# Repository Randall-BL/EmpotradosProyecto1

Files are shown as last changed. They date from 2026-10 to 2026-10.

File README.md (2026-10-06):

# Proyecto I — Robot Aspiradora Autónomo con Yocto

Curso **CE-1113 Sistemas Empotrados** — Instituto Tecnológico de Costa Rica
Robot aspiradora autónomo sobre **Raspberry Pi 4 Model B** con una imagen Linux mínima
construida con **Yocto Project (Poky, rama `scarthgap`)**.

El robot navega de forma autónoma evadiendo obstáculos con un radar ultrasónico (un
HC-SR04 sobre un servo de 180°) y un MPU-6050 que da su velocidad y el tiempo que falta
para chocar; reproduce MP3 por un amplificador PAM8403, y se controla remotamente desde
un servidor web embebido que muestra telemetría, el radar y el mapa de recorrido en
tiempo real. Todo el acceso al hardware pasa por una biblioteca dinámica propia
(`librobot.so`) compilada de forma cruzada para ARM.

> Estado del proyecto y desglose de tareas: [`TODO.md`](TODO.md) y los
> [issues del repositorio](https://github.com/Randall-BL/EmpotradosProyecto1/issues).

## Contenido

1. [Arquitectura del sistema](#1-arquitectura-del-sistema)
2. [Estructura del repositorio](#2-estructura-del-repositorio)
3. [Instalación](#3-instalación)
4. [Generación de la imagen Yocto](#4-generación-de-la-imagen-yocto)
5. [Compilación con la toolchain](#5-compilación-con-la-toolchain)
6. [Configuración y uso](#6-configuración-y-uso)
7. [API de la biblioteca dinámica](#7-api-de-la-biblioteca-dinámica)
8. [Paquetes agregados y su justificación](#8-paquetes-agregados-y-su-justificación)
9. [Evidencias de compilación cruzada](#9-evidencias-de-compilación-cruzada)
10. [Métricas de eficiencia de recursos](#10-métricas-de-eficiencia-de-recursos)
11. [Resultados](#11-resultados)
12. [Pruebas sin hardware](#12-pruebas-sin-hardware)
13. [Documentación](#13-documentación)
14. [Flujo de trabajo y licencia](#14-flujo-de-trabajo-y-licencia)

---

## 1. Arquitectura del sistema

### 1.1 Hardware

Dos fuentes independientes: un power bank USB alimenta la Raspberry Pi y todo lo que
trabaja a 5 V, y dos baterías alcalinas de 9 V en paralelo alimentan el puente H y los
motores. Las cuatro señales que cruzan del dominio lógico al de potencia —las entradas
del puente H— lo hacen por optoacopladores, y las dos tierras no se tocan en ningún
punto.

```mermaid
flowchart TB
    PB["Power bank USB · 5 V"]
    BAT["2 baterías de 9 V en paralelo"]

    subgraph LOG["Dominio lógico · GND_LOG"]
        PI["Raspberry Pi 4"]
        SERVO["Servo del radar"]
        HC["HC-SR04<br/>divisor 1k/2k en ECHO"]
        MPU["MPU-6050 (GY-521)"]
        IR["2 sensores IR al piso<br/>TCRT5000 / FC-51 a 3.3 V"]
        LED["4 LEDs indicadores"]
        AMP["Filtro RC + PAM8403"]
        SPK["Parlante 8 Ω"]
    end

    OPTO{{"4 × PC817 · aislamiento óptico"}}

    subgraph POT["Dominio de potencia · GND_POT"]
        L298["L298N"]
        MOT["2 motores DC"]
    end

    PB -- "USB-C" --> PI
    BAT -- "9 V" --> L298 --> MOT
    PI -- "5 V · GPIO 25" --> SERVO
    PI -- "GPIO 17 / 27" --- HC
    PI -- "I2C · GPIO 2 / 3" --- MPU
    PI -- "GPIO 4 / 8" --- IR
    PI -- "GPIO 16 · 20 · 21 · 26" --> LED
    PI -- "GPIO 18 · PWM" --> AMP --> SPK
    PI -. "GPIO 5 · 6 · 23 · 24" .-> OPTO
    OPTO -. "IN1–IN4" .-> L298
```

Los esquemas eléctricos dibujados están en
[`documentación/hardware-diagramas.pdf`](documentación/hardware-diagramas.pdf).

| Función | GPIO (BCM) | Nota |
|---|---|---|
| Motor derecho `IN1` / `IN2` (salida A) | 5 / 6 | Vía optoacoplador; `ENA` con jumper en el L298N |
| Motor izquierdo `IN3` / `IN4` (salida B) | 23 / 24 | Vía optoacoplador; `ENB` con jumper |
| Servo del radar | 25 | Señal directa; se alimenta de los 5 V de la Raspberry Pi |
| HC-SR04 `TRIG` / `ECHO` | 17 / 27 | `ECHO` con divisor 1 kΩ / 2 kΩ: el sensor entrega 5 V |
| MPU-6050 `SDA` / `SCL` | 2 / 3 | Módulo GY-521, alimentado de los 5 V de la Raspberry Pi |
| LED encendido / autónomo / manual / obstáculo | 16 / 20 / 21 / 26 | 5 mA cada uno |
| Sensores IR de desnivel izquierdo / derecho | 4 / 8 | Opcional. Módulos a 3.3 V, entradas con pull-down: sin módulo se lee "hay piso" |
| Audio PWM | 18 | Overlay `audremap`, filtro RC y PAM8403 |

El detalle —cálculos, listas de materiales y procedimientos de verificación— está en
[`docs/hardware-pinout.md`](docs/hardware-pinout.md),
[`docs/hardware-aislamiento.md`](docs/hardware-aislamiento.md),
[`docs/hardware-alimentacion.md`](docs/hardware-alimentacion.md),
[`docs/hardware-sensores.md`](docs/hardware-sensores.md) y
[`docs/hardware-chasis.md`](docs/hardware-chasis.md).

**Desviaciones acordadas con el profesor.** El diseño se aparta del enunciado en dos
puntos, ambos consultados con el profesor:

| Punto del enunciado | Lo que hace el robot | Motivo |
|---|---|---|
| Velocidad de los motores por PWM | Avanza, retrocede, gira y frena a velocidad fija, sin PWM | Los motores son lentos y de alto torque (60 rpm a 12 V) y trabajan a unos 9 V: con la tensión recortada por la PWM el robot no se mueve. Ver [`docs/hardware-aislamiento.md`](docs/hardware-aislamiento.md#velocidad-fija) |
| Al menos dos sensores de proximidad | Un HC-SR04 sobre un servo, que cubre el frente y los lados, y un MPU-6050 | El profesor lo consideró suficiente: lo que busca es que el robot tenga dos sensores. Ver [`docs/hardware-sensores.md`](docs/hardware-sensores.md) |

### 1.2 Software

```mermaid
flowchart TB
    WEB["Navegador del celular o la PC<br/>login.html · dashboard.html"]

    subgraph IMG["Imagen robot-image · Yocto scarthgap · systemd"]
        subgraph SRV["robot-server"]
            API["API REST y autenticación<br/>libmicrohttpd"]
            NAV["Hilo de navegación a 10 Hz<br/>evasión y mapa de 31 × 31"]
        end
        subgraph LIB["librobot.so.1"]
            MOTORES["lib_motors"]
            RADAR["lib_radar · lib_servo · lib_sensors<br/>hilo de barrido"]
            ODOM["lib_odom · lib_imu<br/>hilo de 50 Hz"]
            LEDS["lib_leds"]
            AUDIO["lib_audio<br/>hilo de reproducción"]
        end
        PIG["pigpiod<br/>GPIO · PWM y servo por DMA · I2C"]
        SND["mpg123 y ALSA"]
    end

    HW["L298N · servo · HC-SR04 · MPU-6050 · LEDs · PAM8403"]

    WEB -- "HTTP 8080 · JSON · cada 500 ms" --> API
    API --> NAV
    SRV -- "única vía de acceso al hardware" --> LIB
    MOTORES --> PIG
    RADAR --> PIG
    ODOM --> PIG
    LEDS --> PIG
    AUDIO --> SND
    PIG --> HW
    SND --> HW
```

| Componente | Qué hace |
|---|---|
| `robot-image` | Imagen sobre `core-image-minimal` con `systemd`, sin interfaz gráfica. La construye la capa propia `meta-robot`. |
| `librobot.so.1` | Biblioteca dinámica propia. Encapsula motores, radar, MPU-6050, odometría, LEDs y audio. Lanza tres hilos: odometría a 50 Hz, barrido del radar y reproducción de audio. |
| `robot-server` | Servidor HTTP en C sobre `libmicrohttpd`. Sirve el panel, expone la API y corre el hilo de navegación. Solo toca el hardware a través de `librobot`. |
| `pigpiod` | Demonio de GPIO. Genera PWM y pulsos de servo por DMA, mide el eco del HC-SR04 y da el bus I2C. Solo escucha en la interfaz local. |
| `robot-server.service` | Unidad `systemd` propia: arranque automático, `Requires=pigpiod.service` y `Restart=on-failure`. |

Cómo navega, cómo estima la velocidad y cómo construye el mapa:
[`docs/navegacion-radar.md`](docs/navegacion-radar.md).

---

## 2. Estructura del repositorio

```
.
├── lib/                    Biblioteca dinámica librobot.so (motores, radar, MPU-6050, LEDs, audio)
├── server/                 Servidor web embebido en C
│   ├── src/                  Código del servidor (API REST, autenticación, estado)
│   └── www/                  Interfaz web estática (login + dashboard)
├── audio/                  Recursos de audio
│   ├── notify_*.mp3          Sonidos de los 4 eventos del sistema
│   ├── canciones/            Playlist versionada, de dominio público
│   └── music/                Música propia (no se versiona, ver audio/README.md)
├── meta-robot/             Capa Yocto propia del proyecto
│   ├── conf/                 layer.conf, local.conf.sample y la máquina de QEMU
│   ├── recipes-image/        Receta de la imagen final (robot-image)
│   ├── recipes-multimedia/   Receta de librobot
│   ├── recipes-robot/        Receta del servidor web + unidad systemd
│   ├── recipes-support/      Receta de pigpio
│   ├── recipes-audio/        Configuración de ALSA
│   ├── recipes-connectivity/ Configuración de WiFi para arranque headless
│   ├── recipes-bsp/          Ajustes de config.txt y cmdline.txt
│   ├── recipes-kernel/       Fragmentos de configuración del kernel
│   └── wic/                  Tabla de particiones de la microSD
├── sim/                    Simulador de hardware: prueba librobot y el servidor sin la Raspberry
├── scripts/                Grabado de la microSD, medición de métricas, generación de la playlist
├── docs/                   Documentación técnica y evidencias
├── modelo-3d/              Carcasa impresa en 3D: modelo paramétrico (CadQuery), STL, STEP y vistas
├── documentación/          Documentos DI y AC, y diagramas de hardware (LaTeX y PDF)
├── CONTRIBUTING.md         Flujo de trabajo Git y convenciones de código
├── NOTICE.md               Atribución de software de terceros
└── TODO.md                 Desglose completo de requerimientos del enunciado
```

Los directorios de build de Yocto (`build/`, `tmp/`, `sstate-cache/`, `downloads/`) y los
artefactos de compilación (`*.o`, `*.so`, `CMakeFiles/`) están excluidos vía
[`.gitignore`](.gitignore): solo se versiona código fuente, recetas y documentación.

---

## 3. Instalación

### 3.1 Requisitos del host

Ubuntu 22.04 o 24.04, o Debian 12, de 64 bits.

| Recurso | Mínimo | Recomendado |
|---|---|---|
| Espacio en disco | 100 GB | 150 GB |
| RAM | 8 GB | 16 GB |
| Primer build | más de 5 horas | menos con más núcleos |

```bash
sudo apt update
sudo apt install -y gawk wget git diffstat unzip texinfo gcc build-essential \
    chrpath socat cpio python3 python3-pip python3-pexpect xz-utils \
    debianutils iputils-ping python3-git python3-jinja2 python3-subunit \
    zstd liblz4-tool file locales libacl1 bmap-tools
sudo locale-gen en_US.UTF-8
```

El build no puede hacerse sobre NTFS, exFAT ni un directorio de red. Con 8 GB de RAM o
menos hay que limitar el paralelismo: ver
[Hosts con poca memoria](docs/yocto-setup.md#hosts-con-poca-memoria).

### 3.2 Obtener el código

Poky, las capas y este repositorio, todos en la rama `scarthgap`:

```bash
mkdir -p ~/yocto && cd ~/yocto
git clone -b scarthgap https://git.yoctoproject.org/poky.git
cd poky
git clone -b scarthgap https://github.com/agherzan/meta-raspberrypi.git
git clone -b scarthgap https://github.com/openembedded/meta-openembedded.git
cd ..
git clone https://github.com/Randall-BL/EmpotradosProyecto1.git
```

---

## 4. Generación de la imagen Yocto

El procedimiento completo, con solución de problemas, está en
[`docs/yocto-setup.md`](docs/yocto-setup.md).

### 4.1 Agregar la capa `meta-robot/`

```bash
cd ~/yocto/poky
source oe-init-build-env            # crea build/ y deja la shell dentro

bitbake-layers add-layer ../meta-raspberrypi
bitbake-layers add-layer ../meta-openembedded/meta-oe
bitbake-layers add-layer ../meta-openembedded/meta-python
bitbake-layers add-layer ../meta-openembedded/meta-multimedia
bitbake-layers add-layer ../meta-openembedded/meta-networking
bitbake-layers add-layer ~/yocto/EmpotradosProyecto1/meta-robot

bitbake-layers show-layers          # deben aparecer las 8 capas
```

`meta-robot` se agrega **desde su ubicación dentro del repositorio clonado**. Las
recetas toman sus fuentes de `lib/`, `server/` y `audio/`, en la raíz del repositorio,
mediante `FILESEXTRAPATHS`: si se copia solo la carpeta de la capa, `do_fetch` falla.

### 4.2 Configurar el build

```bash
cat ~/yocto/EmpotradosProyecto1/meta-robot/conf/local.conf.sample >> conf/local.conf
```

Ese archivo lleva comentada la razón de cada variable. Lo esencial:

```
MACHINE ?= "raspberrypi4-64"
DISTRO_FEATURES:append = " systemd usrmerge wifi"
VIRTUAL-RUNTIME_init_manager = "systemd"
DISABLE_VC4GRAPHICS = "1"
ENABLE_I2C = "1"
RPI_KERNEL_DEVICETREE_OVERLAYS:append:rpi = " overlays/audremap.dtbo"
```

### 4.3 Credenciales de WiFi

El arranque es headless: el robot se conecta solo a la red. El archivo real está en
`.gitignore` y nunca se sube.

```bash
cd ~/yocto/EmpotradosProyecto1/meta-robot/recipes-connectivity/wifi-config/files
cp wpa_supplicant-wlan0.conf.sample wpa_supplicant-wlan0.conf
$EDITOR wpa_supplicant-wlan0.conf   # SSID y contraseña de la red
```

Si se omite, la receta usa la plantilla y `bitbake` avisa con un `WARNING`: la imagen se
construye igual, pero el robot no se conecta. Así un clon limpio produce la imagen sin
pasos manuales.

### 4.4 Construir

```bash
cd ~/yocto/poky/build
bitbake robot-image
```

Resultado:
`tmp/deploy/images/raspberrypi4-64/robot-image-raspberrypi4-64.rootfs.wic.bz2`.

### 4.5 Las recetas propias

| Receta | Qué integra |
|---|---|
| [`librobot_1.0.bb`](meta-robot/recipes-multimedia/librobot/librobot_1.0.bb) | La biblioteca dinámica de control |
| [`robot-server_1.0.bb`](meta-robot/recipes-robot/robot-server/robot-server_1.0.bb) | El servidor web, la interfaz, los audios y la unidad `systemd` |
| [`pigpio_1.0.bb`](meta-robot/recipes-support/pigpio/pigpio_1.0.bb) | `pigpio` desde su repositorio, con `SRCREV` fijo, y `pigpiod.service` |
| [`alsa-config_1.0.bb`](meta-robot/recipes-audio/alsa-config/alsa-config_1.0.bb) | `asound.conf` que dirige el audio a la salida PWM |
| [`wifi-config.bb`](meta-robot/recipes-connectivity/wifi-config/wifi-config.bb) | Credenciales de WiFi y configuración de red |
| [`robot-image.bb`](meta-robot/recipes-image/images/robot-image.bb) | La imagen final |

Cómo cumple `librobot_1.0.bb` lo que pide el enunciado:

```bitbake
# Copia las fuentes: viven en lib/, en la raíz del repositorio
FILESEXTRAPATHS:prepend := "${THISDIR}/../../../lib:${THISDIR}/../../..:"
SRC_URI = "file://lib_motors.c;subdir=lib file://lib_motors.h;subdir=lib ... \
           file://CMakeLists.txt;subdir=lib file://LICENSE;subdir=lib"
S = "${WORKDIR}/lib"

# Declara las dependencias de compilación y de ejecución
DEPENDS = "mpg123 alsa-lib"
DEPENDS:append:rpi = " pigpio"
RDEPENDS:${PN}:rpi = "pigpio-bin-pigpiod"

# Invoca CMake con la toolchain de Yocto
inherit cmake

# Instala los artefactos: el .so en la imagen, los headers en el paquete -dev
FILES:${PN}     = "${libdir}/librobot.so.1*"
FILES:${PN}-dev = "${libdir}/librobot.so ${includedir}/robot/*.h"
```

`robot-server_1.0.bb` agrega la unidad `systemd`, habilitada desde la receta y no a mano
en el target:

```bitbake
DEPENDS = "libmicrohttpd librobot"
inherit cmake systemd
SYSTEMD_SERVICE:${PN} = "robot-server.service"
SYSTEMD_AUTO_ENABLE = "enable"
```

El contenido de la capa está descrito en [`meta-robot/README.md`](meta-robot/README.md).

### 4.6 Grabar la microSD

```bash
./scripts/grabar-sd.sh              # busca la tarjeta, pide confirmación y verifica
```

O a mano:

```bash
cd tmp/deploy/images/raspberrypi4-64/
bzip2 -dk robot-image-raspberrypi4-64.rootfs.wic.bz2
lsblk                               # identificar el dispositivo antes de escribir
sudo bmaptool copy --nobmap robot-image-raspberrypi4-64.rootfs.wic /dev/sdX
```

La tarjeta queda con tres particiones, ninguna de más de 200 MB: `boot` (130 MiB),
`root` (180 MiB) y `canciones` (180 MiB).

---

## 5. Compilación con la toolchain

Nada se compila en la Raspberry Pi: la imagen no trae compilador. Además del build de
BitBake, el Toolchain-SDK permite compilar y probar un cambio sin reconstruir la imagen.
Detalle en [`docs/sdk.md`](docs/sdk.md).

### 5.1 Generar e instalar el SDK

```bash
cd ~/yocto/poky && source oe-init-build-env
bitbake -c populate_sdk robot-image

./tmp/deploy/sdk/poky-glibc-x86_64-robot-image-cortexa72-raspberrypi4-64-toolchain-*.sh \
    -y -d ~/robot-sdk
```

### 5.2 Compilar la biblioteca y el servidor

```bash
source ~/robot-sdk/environment-setup-cortexa72-poky-linux

cd ~/yocto/EmpotradosProyecto1/lib
mkdir -p build && cd build
cmake -DCMAKE_TOOLCHAIN_FILE=$OECORE_NATIVE_SYSROOT/usr/share/cmake/OEToolchainConfig.cmake ..
make -j$(nproc)

cd ~/yocto/EmpotradosProyecto1/server/src
mkdir -p build && cd build
cmake -DCMAKE_TOOLCHAIN_FILE=$OECORE_NATIVE_SYSROOT/usr/share/cmake/OEToolchainConfig.cmake ..
make -j$(nproc)
```

Cada terminal nueva necesita su `source`. Si `cmake` toma el compilador del host, casi
siempre faltó ese paso.

### 5.3 Verificar y probar en el target

```bash
file librobot.so.1.0.0
# ELF 64-bit LSB shared object, ARM aarch64, version 1 (SYSV), dynamically linked

scp librobot.so.1.0.0 root@<ip-del-robot>:/usr/lib/
scp robot-server      root@<ip-del-robot>:/usr/bin/
ssh root@<ip-del-robot> 'ldconfig && systemctl restart robot-server'
```

Sirve para iterar. Lo que se entrega es la imagen que produce `bitbake robot-image`.

---

## 6. Configuración y uso

### 6.1 Primer arranque

1. Insertar la microSD y encender el interruptor principal.
2. El robot arranca solo, sin pantalla ni teclado. Cuando el servidor está listo se
   enciende el **LED verde** y suena el aviso de inicio. Hay que dejarlo quieto en el
   piso durante ese primer segundo: el MPU-6050 se calibra al arrancar.
3. Buscar la IP que tomó el robot en la lista de clientes del router o del punto de
   acceso. También sirve la consola serie (115200 8N1) y
   `ip a`.

### 6.2 Panel de control

Abrir `http://<ip-del-robot>:8080` desde el celular o la PC, en la misma red.

| | |
|---|---|
| Usuario | `user1` |
| Contraseña | `password1` |

La sesión caduca a los 10 minutos de inactividad. El panel tiene tres pestañas:

| Pestaña | Qué ofrece |
|---|---|
| **Control** | Botones de modo autónomo y manual, ciclo de limpieza (meta por tiempo o por área, progreso y aviso de fin), controles direccionales, velocidad, estado de los cuatro LEDs y de los sensores de desnivel. Los motores van a velocidad fija, así que el control de velocidad no cambia la velocidad real |
| **Mapa** | La grilla de recorrido, el radar con las distancias a la izquierda, al frente y a la derecha, la velocidad que da el MPU-6050 y el tiempo antes de chocar, en tiempo real |
| **Audio** | Lista de canciones, reproducir, pausar, detener y volumen, y la playlist persistente: agregar con `+`, reordenar con ▲ ▼, quitar con ✕ y reproducirla completa |

### 6.3 Modos de operación

- **Autónomo.** El robot avanza y, al detectar un obstáculo, se detiene, retrocede, mira
  alrededor con el radar y gira hacia el lado más libre. Los controles direccionales
  quedan bloqueados.
- **Manual.** Los controles direccionales mandan los motores mientras se mantienen
  presionados. En la PC también funcionan las flechas y `W` `A` `S` `D`; la barra
  espaciadora detiene. Si aparece un obstáculo al frente, el robot frena solo.

**Desnivel (opcional).** Dos sensores infrarrojos en las esquinas delanteras miran al
piso. Si uno deja de ver piso —el borde de una grada—, el robot frena en cualquier modo.
En autónomo además retrocede y gira hacia el lado contrario (con los dos sensores, media
vuelta); en manual se niega a avanzar (`409`) hasta que se retroceda o se gire.

**Ciclo de limpieza (opcional).** Desde la pestaña Control se fija una meta: minutos en
modo autónomo o metros cuadrados recorridos (celdas nuevas del mapa × 0.09 m²). Al
cumplirla el robot se detiene, suena el aviso de fin de ciclo y el panel muestra
"Ciclo completado". Sigue quieto hasta que se pulse **Nuevo ciclo** o se vuelva a pedir
el modo autónomo.

### 6.4 Indicadores y sonidos

| LED | Color | Significado |
|---|---|---|
| Encendido | Verde | Sistema energizado y servidor activo |
| Autónomo | Azul | Modo autónomo en curso |
| Manual | Amarillo | Modo manual en curso |
| Obstáculo | Rojo | Obstáculo o desnivel detectado |

Hay un sonido para cada evento: inicio del sistema, inicio del modo autónomo, obstáculo
o desnivel detectado, cambio a modo manual y fin del ciclo de limpieza. El aviso pausa la
música y la reanuda al terminar.

### 6.5 Audio

Las canciones están en `/opt/robot/audio/canciones/`, en su propia partición. Una pista
elegida suelta se repite hasta que se detiene o se elige otra.

**Playlist persistente (opcional).** La lista ordenada que se arma en la pestaña Audio se
guarda en `/opt/robot/audio/canciones/playlist.txt`, un nombre de archivo por línea, en
la partición de la música: sobrevive a los reinicios. Se escribe en un temporal y se
renombra, así un corte de energía no la deja a medias. "Reproducir playlist" recorre la
lista en orden y vuelve a empezar al terminar. Sin archivo, la playlist son todas las
canciones.

Para agregar música:

- **Antes de construir:** copiar los MP3 a `audio/music/` (no se versiona).
- **Con el robot en marcha:** `scp cancion.mp3 root@<ip>:/opt/robot/audio/canciones/` y
  reiniciar el servicio.

### 6.6 Mapa de recorrido

Grilla de 31 × 31 celdas de 30 cm, con el robot empezando en el centro.

| Estado | Cuándo |
|---|---|
| Visitada | El centro del robot estuvo en la celda |
| Obstáculo | Un eco del radar cayó en la celda |
| Desconocida | Todo lo demás |

### 6.7 API HTTP

Todos los endpoints salvo el login exigen la cookie de sesión.

| Método y ruta | Cuerpo | Qué hace |
|---|---|---|
| `POST /api/login` | `{"username","password"}` | Inicia sesión |
| `POST /api/logout` | — | Cierra la sesión |
| `GET /api/status` | — | Modo, sensores, radar, movimiento, LEDs, audio y mapa |
| `POST /api/mode` | `{"mode":"autonomous"}` o `"manual"` | Cambia de modo |
| `POST /api/move` | `{"direction":"forward","speed":70}` | Mueve el robot, solo en modo manual. `direction`: `forward`, `backward`, `left`, `right`, `stop` |
| `GET /api/audio/list` | — | Lista de pistas |
| `POST /api/audio/control` | `{"action":"play","track_id":1}` | `play`, `pause`, `resume`, `stop`, `play_playlist` con `"index"`, o `seek` con `"position"` en segundos (la barra de progreso del panel) |
| `POST /api/audio/volume` | `{"volume":55}` | Volumen de 0 a 100 |
| `GET /api/audio/playlist` | — | Ids de la playlist en orden y la posición que suena |
| `POST /api/audio/playlist` | `{"ids":[3,1,9]}` | Reemplaza la playlist y la guarda en la SD |
| `POST /api/ciclo` | `{"tipo":"tiempo","minutos":5}`, `{"tipo":"area","m2":4}`, `{"tipo":"off"}` o `{"accion":"nuevo"}` | Configura la meta del ciclo de limpieza o empieza uno nuevo |

`GET /api/status` incluye además `ciclo` (tipo, meta, avance, `completo`) y `caida`
(sensores izquierdo y derecho, y eventos).

### 6.8 Cambiar la configuración

| Qué | Dónde | Después |
|---|---|---|
| Red WiFi | `wpa_supplicant-wlan0.conf` de la receta `wifi-config` | `bitbake -c cleansstate wifi-config && bitbake robot-image` |
| Usuario y contraseña | Tabla de usuarios en `server/src/auth.c`; el resumen sale de `echo -n 'clave' \| sha256sum` | Reconstruir la imagen |
| Umbrales de obstáculo y velocidades | Constantes de `server/src/main.c` y `lib/*.h` | Ver [`docs/odometria.md`](docs/odometria.md) |
| Pines | `#define` de la biblioteca | Ver [`docs/hardware-pinout.md`](docs/hardware-pinout.md) |

### 6.9 Diagnóstico

El robot no tiene pantalla: todo va al journal.

```bash
systemctl status robot-server
journalctl -u robot-server -f       # en vivo
journalctl -u pigpiod -b
```

Arranque automático y recuperación ante fallos:
[`docs/arranque-automatico.md`](docs/arranque-automatico.md).

---

## 7. API de la biblioteca dinámica

`librobot.so.1` es la única vía de acceso al hardware. Se enlaza con `-lrobot` y sus
headers están bajo `robot/`. Toda función que devuelve `int` usa `0` para éxito y `-1`
para error; las lecturas de distancia devuelven `-1.0` si no hubo eco.

La referencia completa, con tipos y ejemplos, está en
[`docs/api-librobot.md`](docs/api-librobot.md).

| Módulo | Funciones |
|---|---|
| **Fachada** `lib_robot.h` | `robot_init()` · `robot_shutdown()` · `robot_activo()` · `robot_distancia_frontal()` · `robot_distancia_izquierda()` · `robot_distancia_derecha()` |
| **Motores** `lib_motors.h` | `motores_set(izq, der)` · `motores_get()` · `motores_detener()` · `motores_avanzar(v)` · `motores_retroceder(v)` · `motores_girar_izquierda(v)` · `motores_girar_derecha(v)` · `motores_curva(v, giro)` |
| **Sensor** `lib_sensors.h` | `sensor_init()` · `sensor_leer_distancia()` |
| **Servo** `lib_servo.h` | `servo_init()` · `servo_mover(grados)` · `servo_angulo()` · `servo_liberar()` |
| **Radar** `lib_radar.h` | `radar_iniciar()` · `radar_detener()` · `radar_pausar()` · `radar_angulo_actual()` · `radar_lecturas()` · `radar_distancia(angulo)` · `radar_seq()` · `radar_barrido_completo()` · `radar_esperar_barrido()` · `radar_tiempo_choque()` · `radar_estado_choque()` · `radar_rayo()` |
| **Desnivel** `lib_caida.h` | `caida_init()` · `caida_leer()` |
| **MPU-6050** `lib_imu.h` | `imu_init()` · `imu_calibrar()` · `imu_leer()` · `imu_disponible()` · `imu_cerrar()` |
| **LEDs** `lib_leds.h` | `lib_leds_init()` · `lib_leds_set(led, estado)` · `lib_leds_get(led)` · `lib_leds_sync_from_state()` · `lib_leds_destroy()` |
| **Odometría** `lib_odom.h` | `odom_init()` · `odom_arrancar()` · `odom_parar()` · `odom_reset()` · `odom_update()` · `odom_get(x, y, rumbo)` · `odom_velocidad_cm_s()` · `odom_avance_cm()` · `odom_distancia_recorrida()` · `odom_get_velocidades()` · `odom_usa_imu()` |
| **Audio** `lib_audio.h` | `lib_audio_init(dir)` · `lib_audio_destroy()` · `lib_audio_scan()` · `lib_audio_get_tracks()` · `lib_audio_play(id)` · `lib_audio_pause()` · `lib_audio_resume()` · `lib_audio_stop()` · `lib_audio_seek(segundos)` · `lib_audio_set_volume(v)` · `lib_audio_get_volume()` · `lib_audio_get_status()` · `lib_audio_get_current_id()` · `lib_audio_get_position()` · `lib_audio_notify(evento)` · `lib_audio_playlist_get()` · `lib_audio_playlist_set()` · `lib_audio_play_playlist(pos)` · `lib_audio_playlist_pos()` |

Ejemplo mínimo:

```c
#include <robot/lib_robot.h>
#include <robot/lib_motors.h>
#include <robot/lib_radar.h>

int main(void) {
    if (robot_init() != 0) return 1;            /* con el robot quieto: calibra el MPU */
    while (trabajando) {
        double f   = robot_distancia_frontal();
        double ttc = radar_tiempo_choque();
        if ((f > 0 && f < 20.0) || (ttc >= 0 && ttc < 1.2))
            motores_detener();                  /* evadir */
        else
            motores_avanzar(200);
        usleep(100000);                         /* la odometría y el radar corren solos */
    }
    robot_shutdown();
    return 0;
}
```

---

## 8. Paquetes agregados y su justificación

La imagen parte de `core-image-minimal`, el punto de partida más pequeño de Poky. Todo lo
que se agrega está aquí; la discusión completa, con lo que se dejó fuera a propósito,
está en [`docs/paquetes.md`](docs/paquetes.md).

| Paquete | Justificación |
|---|---|
| `librobot` | Biblioteca dinámica de control. Obligatoria: única vía de acceso al hardware. |
| `robot-server` | Servidor web de control remoto. Obligatorio. |
| `wifi-config` | Credenciales y configuración de `wlan0`. Sin esto el arranque headless no llega a la red. |
| `alsa-config` | `asound.conf` que fuerza la salida PWM analógica. Sin esto ALSA elige HDMI. |
| `libmicrohttpd` | Servidor HTTP enlazable en C: un proceso menos que nginx o lighttpd, y pocos cientos de KB. |
| `mpg123` | Decodificador MP3, el más liviano con API en C. GStreamer traería decenas de MB. |
| `alsa-utils` | `amixer` para el control de volumen y `aplay` para diagnosticar la salida de audio. |
| `alsa-lib` | Runtime de ALSA; entra como dependencia de `librobot` y `mpg123`. |
| `pigpio`, `libpigpio`, `libpigpio_if2` | Acceso a GPIO con pulsos de servo de temporización estable, medición del eco en microsegundos e I2C. |
| `pigpio-bin-pigpiod` | El demonio al que se conecta `librobot`. |
| `wpa-supplicant` | Autenticación WPA2: la única forma de que un sistema headless se una solo a la red. |
| `wireless-regdb-static` | Base regulatoria; sin ella el kernel restringe canales y potencia. |
| `linux-firmware-rpidistro-bcm43455` | Firmware del chip WiFi de la Raspberry Pi 4. |
| `iw`, `rfkill` | Diagnóstico del enlace inalámbrico sin pantalla. Pocos KB. |
| `kernel-module-brcmfmac`, `-brcmfmac-wcc`, `-brcmutil` | Driver del chip WiFi Broadcom. |
| `kernel-module-snd`, `-snd-pcm`, `-snd-bcm2835` | Subsistema de sonido y driver de la salida de audio. |
| `kernel-module-i2c-bcm2835`, `-i2c-dev` | Bus I2C del MPU-6050. |
| `dhcpcd` | Solo en la imagen de QEMU, donde pide la IP. En la Raspberry la red la lleva `systemd-networkd`. |

Los módulos de kernel se listan uno por uno porque el paquete `kernel-modules` completo
sumaría decenas de MB de drivers que el robot no usa.

**Acceso remoto:** `ssh-server-openssh`, `openssh-sftp-server` y `debug-tweaks` dan
acceso al sistema sin pantalla y permiten recoger las métricas y diagnosticar el robot.

**Fuera a propósito:** entorno gráfico, driver VC4 y Mesa, GStreamer, Python 3,
`i2c-tools`, nginx y lighttpd, Bluetooth y el paquete `kernel-modules` completo.

---

## 9. Evidencias de compilación cruzada

Todas están en [`docs/evidencias/`](docs/evidencias/), generadas en un build real de
`bitbake robot-image`: host x86_64, target `raspberrypi4-64` (Cortex-A72).

### 9.1 Fragmento del log de Yocto

De `tmp/work/cortexa72-poky-linux/librobot/1.0/temp/log.do_compile`, con las rutas
abreviadas. El compilador es el cruzado, `aarch64-poky-linux-gcc`, invocado desde el
`recipe-sysroot-native`; el `gcc` del host no interviene.

```
[1/6] …/recipe-sysroot-native/usr/bin/aarch64-poky-linux/aarch64-poky-linux-gcc
      --sysroot=…/librobot/1.0/recipe-sysroot -Drobot_EXPORTS …
[5/6] : && …/aarch64-poky-linux-gcc --sysroot=…/recipe-sysroot -fPIC
      -mcpu=cortex-a72+crc -mbranch-protection=standard -fstack-protector-strong
      -O2 -D_FORTIFY_SOURCE=2 …
```

Los fragmentos sin abreviar:
[`librobot`](docs/evidencias/log.do_compile.librobot.txt),
[`robot-server`](docs/evidencias/log.do_compile.robot-server.txt) y
[`pigpio`](docs/evidencias/log.do_compile.pigpio.txt).

### 9.2 Los binarios son ARM y el servidor usa la biblioteca

De [`binarios-target.md`](docs/evidencias/binarios-target.md):

```
librobot.so.1.0.0: ELF 64-bit LSB shared object, ARM aarch64, version 1 (SYSV), dynamically linked, …
robot-server: ELF 64-bit LSB pie executable, ARM aarch64, version 1 (SYSV), dynamically linked,
              interpreter /usr/lib/ld-linux-aarch64.so.1, for GNU/Linux 5.15.0, stripped

  NEEDED               libmicrohttpd.so.12
  NEEDED               librobot.so.1
  NEEDED               libm.so.6
  NEEDED               libc.so.6
  NEEDED               ld-linux-aarch64.so.1
```

El servidor no enlaza `libpigpiod_if2`: el acceso a GPIO queda dentro de `librobot.so.1`.
Los binarios analizados tienen el mismo md5 que los que corren en la Raspberry Pi 4.

Un binario compilado con el SDK no corre en el host
([`sdk-prueba.md`](docs/evidencias/sdk-prueba.md)):

```
$ ./hola_sdk
bash: ./hola_sdk: no se puede ejecutar fichero binario: Formato de ejecutable incorrecto
```

### 9.3 Ejecución del binario ARM

El programa de prueba de la biblioteca, compilado con el SDK y ejecutado bajo
`qemu-aarch64`. Extracto de
[`ejecucion-cruzada-qemu.md`](docs/evidencias/ejecucion-cruzada-qemu.md), capturado
cuando la prueba tenía 18 comprobaciones; hoy son 47:

```
$ qemu-aarch64 -L $SDKTARGETSYSROOT ./prueba_librobot_arm

== Arranque ==
  [OK ] robot_init() abre la sesion con el hardware
  [OK ] robot_activo() lo confirma
…
== Motores: control diferencial ==
  [OK ] motores_set guarda la velocidad de cada motor
  [OK ] con el motor izquierdo mas rapido describe una curva a la derecha
  [OK ] motores_set satura en +-255
…
== Cierre ==
  [OK ] robot_shutdown cierra la sesion
  [OK ] los motores quedan detenidos

TODAS LAS PRUEBAS PASARON   (18/18)
```

La imagen completa arrancando en la máquina `qemuarm64-robot`, con `robot-server`
habilitado y activo desde la receta: [`docs/qemu.md`](docs/qemu.md).

### 9.4 Ejecución en la Raspberry Pi 4

Salida completa en [`ejecucion-target.md`](docs/evidencias/ejecucion-target.md),
capturada el 5 de octubre de 2026:

```
$ uname -a
Linux raspberrypi4-64 6.6.63-v8 #1 SMP PREEMPT Fri Dec  6 10:10:05 UTC 2024 aarch64 GNU/Linux

$ systemctl status robot-server
● robot-server.service - Servidor de control del robot aspiradora
     Loaded: loaded (/usr/lib/systemd/system/robot-server.service; enabled; preset: enabled)
     Active: active (running) since Mon 2026-10-05 22:30:23 UTC; 25min ago

$ ls -l /usr/lib/librobot.so*
lrwxrwxrwx    1 root     root            17 Mar  9  2018 /usr/lib/librobot.so.1 -> librobot.so.1.0.0
-rwxr-xr-x    1 root     root         67528 Mar  9  2018 /usr/lib/librobot.so.1.0.0

$ journalctl -u robot-server -b -o short-monotonic | grep -m1 "Servidor escuchando"
[   24.703636] raspberrypi4-64 robot-server[270]: [server] Servidor escuchando en puerto 8080

$ which gcc make cmake; echo $?
1
```

---

## 10. Métricas de eficiencia de recursos

Método, herramientas y justificación completos en [`docs/metricas.md`](docs/metricas.md).

| Métrica | Referencia | Resultado | Herramienta |
|---|---|---|---|
| Rootfs | ≤ 200 MB | **129 MB** | `du` sobre el rootfs de la imagen construida; `df -k /` en el target |
| Tiempo de arranque | ≤ 15 s | **19.2 s** | Relojes monotónicos de `systemd` y `journalctl -o short-monotonic` |
| RAM en operación normal | — | **97 MB** de 1845 MB; `robot-server` 5.2 MB | `MemTotal − MemAvailable` de `/proc/meminfo`; `VmRSS` por proceso |
| CPU en operación normal | — | **3.6 %** de 4 núcleos; `robot-server` 4.5 % de un núcleo | Diferencia de `/proc/stat` y `/proc/PID/stat` en 60 s |

Medido el 5 de octubre de 2026 sobre la imagen final, con el robot armado en modo
autónomo, música sonando y el panel consultando el estado cada 500 ms durante 60 s
(`./scripts/medir-metricas.sh <ip-del-robot>`).

**Rootfs.** Queda en el 65 % del presupuesto. Además, la tabla de particiones fija la
partición raíz en 180 MiB: si la imagen creciera por encima, el build fallaría.

**Arranque.** Excede la referencia en 4.2 s. `robot-server` espera a que la red esté
operativa, y la búsqueda del punto de acceso WiFi se lleva casi 7 s; desde que hay red
el servidor escucha en 1.5 s. Sin red el panel no es alcanzable, así que el servicio no
estaría operativo. Ya se redujo desde 130 s corrigiendo la configuración de red.

**RAM y CPU.** El sistema completo usa el 5 % de la RAM y el 3.6 % de la CPU; queda
margen de sobra en la Raspberry Pi 4.

---

## 11. Resultados

| Resultado | Evidencia |
|---|---|
| La prueba de la biblioteca pasa sus 49 comprobaciones, compilada para ARM bajo `qemu-aarch64` | [`sim/README.md`](sim/README.md), [`docs/navegacion-radar.md`](docs/navegacion-radar.md#6-evidencia-en-el-simulador) |
| Dos minutos en modo autónomo sobre el simulador: 18 evasiones y ningún choque | [`docs/navegacion-radar.md`](docs/navegacion-radar.md#6-evidencia-en-el-simulador) |
| El radar mide los siete ángulos a menos de 2 cm de la distancia real | [`docs/navegacion-radar.md`](docs/navegacion-radar.md#6-evidencia-en-el-simulador) |
| Odometría con MPU-6050: 5 % de error de posición y 0.4° de rumbo en un recorrido en L | [`docs/navegacion-radar.md`](docs/navegacion-radar.md#6-evidencia-en-el-simulador) |
| Desnivel: en el simulador, que tiene una grada que el HC-SR04 no ve, tres minutos en autónomo con una detección, evasión y ninguna caída | [`docs/opcionales.md`](docs/opcionales.md) |
| Ciclo de limpieza: con una meta de 12 s el robot se detuvo a los 12.5 s y sonó el aviso; pedir modo autónomo empezó otro | [`docs/opcionales.md`](docs/opcionales.md) |
| Playlist: se guardó en disco, sobrevivió a un reinicio del servidor y se reprodujo en orden y en bucle | [`docs/opcionales.md`](docs/opcionales.md) |
| El mapa crece en tiempo real: de 79 a 85 celdas visitadas en 6 s | [`docs/evidencias/servidor-web.md`](docs/evidencias/servidor-web.md) |
| La autenticación rechaza credenciales inválidas y protege los endpoints (HTTP 401) | [`docs/evidencias/servidor-web.md`](docs/evidencias/servidor-web.md) |
| Tras un `kill -9`, `systemd` reinicia el servidor solo: PID nuevo y `NRestarts=1` | [`docs/evidencias/systemd-reinicio.md`](docs/evidencias/systemd-reinicio.md) |
| La imagen completa arranca en QEMU y levanta el servicio sola | [`docs/qemu.md`](docs/qemu.md#resultado-de-la-primera-prueba-11-de-setiembre-de-2026) |
| El Toolchain-SDK se genera, se instala y compila para ARM | [`docs/evidencias/sdk-prueba.md`](docs/evidencias/sdk-prueba.md) |
| El arranque del servidor en la Raspberry Pi 4 bajó de 130 s a 17 s | Commit `5890dbb`, [`docs/metricas.md`](docs/metricas.md) |

### Modelo físico

Carcasa circular de 215 mm impresa en 3D, en dos piezas que cierran a presión. El diseño
completo está en [`docs/hardware-chasis.md`](docs/hardware-chasis.md) y los archivos, en
[`modelo-3d/`](modelo-3d/).

| Carcasa armada | Por dentro |
|---|---|
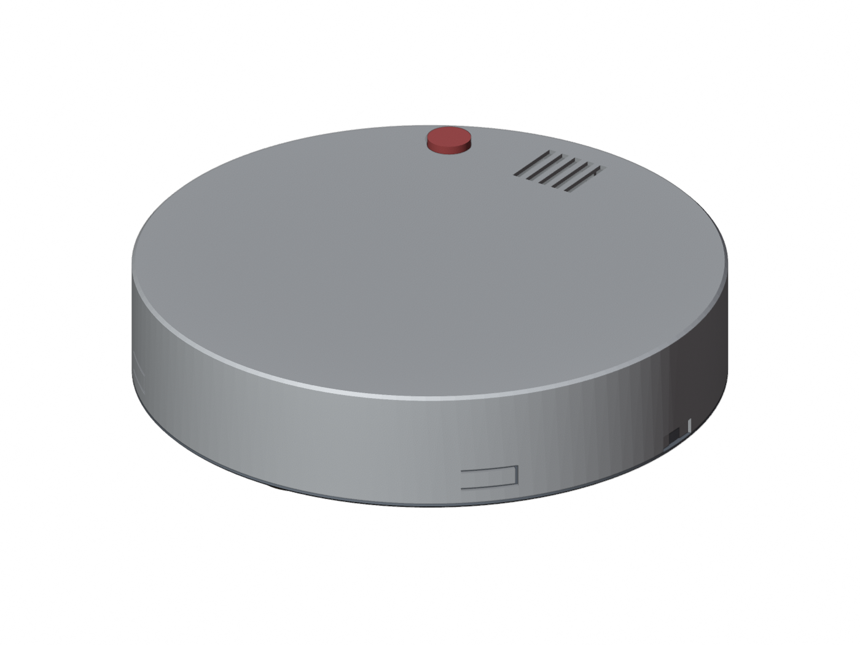
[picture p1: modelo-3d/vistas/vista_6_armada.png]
Carcasa armada
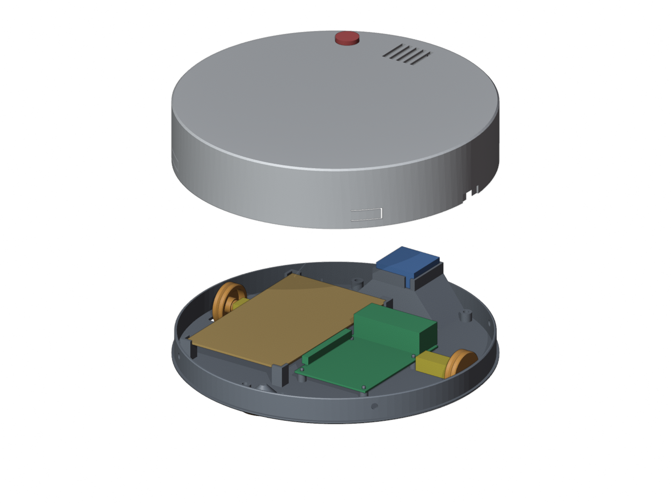
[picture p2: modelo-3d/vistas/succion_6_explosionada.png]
Vista explosionada
|  |  |

Las imágenes son vistas del modelo 3D.

> **PENDIENTE:** fotos del robot armado y un video de la demostración (navegación
> autónoma, modo manual, audio, LEDs y mapa), en `docs/evidencias/`.

---

## 12. Pruebas sin hardware

Cuatro formas de probar sin la Raspberry Pi:

| Qué | Cómo | Prueba |
|---|---|---|
| Biblioteca en la laptop | `cd sim && ./construir.sh && ./prueba_librobot` | `librobot` contra un robot virtual |
| Binario ARM | `sim/construir_arm.sh` | Que la compilación cruzada produce binarios que ejecutan |
| Servidor completo | `sim/construir_servidor.sh && sim/prueba_api.sh` | Cada endpoint, por HTTP |
| Imagen completa | `MACHINE=qemuarm64-robot runqemu robot-image nographic slirp` | Que la imagen arranca y levanta el servicio sola |

El simulador reemplaza a `pigpiod` por un robot virtual en una sala de 4 × 4 m, sin
tocar el código de `lib/`. Ver [`sim/README.md`](sim/README.md) y
[`docs/qemu.md`](docs/qemu.md).

---

## 13. Documentación

| Documento | Contenido |
|---|---|
| [`documentación/documento-diseno.pdf`](documentación/documento-diseno.pdf) | Documento de Diseño (DI1 a DI4) |
| [`documentación/aprendizaje-continuo.pdf`](documentación/aprendizaje-continuo.pdf) | Documento de Aprendizaje Continuo (AC1 a AC4) |
| [`documentación/hardware-diagramas.pdf`](documentación/hardware-diagramas.pdf) | Los diagramas de hardware dibujados |
| [`docs/yocto-setup.md`](docs/yocto-setup.md) | Preparación del host, capas, `local.conf`, build de la imagen y grabado de la microSD |
| [`docs/sdk.md`](docs/sdk.md) | Toolchain-SDK: generación, uso y verificación de la compilación cruzada |
| [`docs/qemu.md`](docs/qemu.md) | La imagen completa en QEMU |
| [`docs/paquetes.md`](docs/paquetes.md) | Justificación de cada paquete incluido en la imagen |
| [`docs/metricas.md`](docs/metricas.md) | Métricas de eficiencia: método, resultados y justificación |
| [`docs/api-librobot.md`](docs/api-librobot.md) | Referencia de la API pública de la biblioteca de control |
| [`docs/navegacion-radar.md`](docs/navegacion-radar.md) | Radar, velocidad con el MPU-6050, tiempo antes de chocar, evasión y mapa |
| [`docs/opcionales.md`](docs/opcionales.md) | Requerimientos opcionales: desnivel, fin de ciclo y playlist persistente |
| [`docs/odometria.md`](docs/odometria.md) | Calibración en campo: motores, servo, MPU-6050, umbrales y odometría |
| [`docs/arranque-automatico.md`](docs/arranque-automatico.md) | Unidades systemd, arranque automático y recuperación ante fallos |
| [`docs/hardware-pinout.md`](docs/hardware-pinout.md) | Mapa de pines GPIO: referencia única del cableado |
| [`docs/hardware-aislamiento.md`](docs/hardware-aislamiento.md) | Etapa de potencia, optoacopladores y separación de tierras |
| [`docs/hardware-alimentacion.md`](docs/hardware-alimentacion.md) | Power bank para la lógica y baterías de 9 V para los motores |
| [`docs/hardware-sensores.md`](docs/hardware-sensores.md) | Radar, MPU-6050, LEDs y audio con PAM8403 |
| [`docs/hardware-chasis.md`](docs/hardware-chasis.md) | Carcasa impresa en 3D, tracción, succión y distribución interna |
| [`modelo-3d/`](modelo-3d/) | Modelo paramétrico de la carcasa, piezas para imprimir y vistas |
| [`docs/evidencias/`](docs/evidencias/) | Logs de compilación cruzada y evidencias de ejecución |
| [`meta-robot/README.md`](meta-robot/README.md) | Contenido de la capa Yocto y cómo agregarla al build |

---

## 14. Flujo de trabajo y licencia

El repositorio usa ramas `main` y `develop` con ramas de trabajo por funcionalidad,
Conventional Commits, Pull Requests e issues agrupados en hitos. Las convenciones están
en [`CONTRIBUTING.md`](CONTRIBUTING.md).

El proyecto se distribuye bajo licencia MIT: ver [`LICENSE`](LICENSE). Parte de la capa
y del código deriva de un proyecto de referencia con la misma licencia; la atribución y
las licencias del software de terceros están en [`NOTICE.md`](NOTICE.md).

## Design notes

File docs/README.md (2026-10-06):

# `docs/` — Documentación técnica y evidencias

## Sistema operativo y build

| Archivo | Contenido |
|---|---|
| `yocto-setup.md` | Preparación del host, layers, `local.conf` y construcción de la imagen |
| `sdk.md` | Generación, instalación y uso del Toolchain-SDK para ARM |
| `qemu.md` | La imagen completa en QEMU (`MACHINE=qemuarm64-robot runqemu robot-image nographic slirp`), sin la Raspberry |
| `api-librobot.md` | Referencia de la API pública de `librobot` (motores, radar, servo, MPU-6050, LEDs, odometría, audio) |
| `navegacion-radar.md` | Barrido del radar, velocidad con el MPU-6050, tiempo antes de chocar, evasión y mapa |
| `opcionales.md` | Los tres requerimientos opcionales: desnivel con sensores IR, fin de ciclo de limpieza y playlist persistente |
| `odometria.md` | Procedimiento de calibración en campo (motores, servo, MPU-6050, umbrales, odometría) |
| `paquetes.md` | Todo paquete agregado sobre la imagen mínima, con su justificación |
| `metricas.md` | Métricas de eficiencia: método, resultados y justificación de las desviaciones |
| `arranque-automatico.md` | Unidades systemd, arranque automático y recuperación ante fallos |

## Hardware

| Archivo | Contenido |
|---|---|
| `hardware-pinout.md` | Mapa de pines GPIO — **referencia única del cableado** |
| `hardware-aislamiento.md` | Etapa de potencia, optoacopladores y separación de tierras |
| `hardware-alimentacion.md` | Power bank para la lógica y baterías de 9 V para los motores |
| `hardware-sensores.md` | Radar (HC-SR04 sobre servo de 180°), MPU-6050, LEDs, audio con PAM8403 y diagrama del dominio lógico |
| `hardware-chasis.md` | Carcasa impresa en 3D, tracción, succión y distribución interna |

> Antes de energizar cualquier cosa, leer `hardware-aislamiento.md` y
> `hardware-sensores.md`. Ambos contienen procedimientos que, si se saltan, destruyen
> la Raspberry Pi.

Los diagramas de hardware dibujados están en
[`../documentación/hardware-diagramas.pdf`](../documentación/hardware-diagramas.pdf),
junto con el Documento de Diseño (`documento-diseno.pdf`) y el de Aprendizaje Continuo
(`aprendizaje-continuo.pdf`).
Aquí se guardan los fragmentos de `log.do_compile` que evidencian la compilación
cruzada y las capturas de ejecución en el target.

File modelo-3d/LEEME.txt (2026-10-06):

CARCASA TIPO ROOMBA - DOS PIEZAS + TRES RUEDAS, SIN TORNILLOS
=============================================================

ARCHIVOS PARA IMPRIMIR (todos vienen en la orientación en que se imprimen, sin soportes)
  carcasa_inferior.stl        Pieza de abajo (piso sobre la cama).                          1 vez
  carcasa_inferior_succion.stl  OTRA VERSIÓN de la pieza de abajo, hecha para aspirar mejor
                              (ver "VERSIÓN DE SUCCIÓN"). Se imprime una de las dos, no ambas.
  boquilla_succion.stl        Boquilla que va debajo de la versión de succión.              1 vez
  carcasa_superior.stl        Pieza de arriba (ya volteada: tapa sobre la cama).            1 vez
  rueda_motriz_x2.stl         Rueda motriz de 30 mm con cubo para eje en D de 3 mm.         2 veces
  rueda_apoyo_aro.stl         Aro que sujeta la bola de la tercera rueda.                   1 vez
  rueda_apoyo_bola_16mm.stl   Bola de 16 mm. Mejor usar una canica de 16 mm: rueda más
                              suave que una bola impresa.                                   1 vez (opcional)

OTROS ARCHIVOS
  *.step               Las mismas piezas para editar en un programa CAD.
  carcasa_roomba.py    Modelo paramétrico (CadQuery). Cambiando los valores del inicio se regenera todo.
  vistas/              Imágenes del diseño.

MEDIDAS
  Diámetro exterior 215 mm. Altura de la carcasa 45 mm; con ruedas queda a 53 mm del suelo.
  El piso queda a 8 mm del suelo.
  Hecha para una cama de 249 x 219 x 269 mm: las dos piezas grandes miden 215 x 215 mm,
  así que sobran 2 mm por lado en Y. Imprimir centrado y sin falda ni borde (skirt/brim) ancho.
  Pieza inferior: 18 mm de alto.  Pieza superior: 43 mm de alto.

PESO (PLA, impreso macizo)
  Carcasa inferior 114 g, carcasa superior 125 g, dos ruedas 9 g, aro 4 g.  Total impreso: unos 250 g.
  Espesores: piso 2.0 mm, tapa 1.6 mm, paredes 1.6 mm.
  Robot completo estimado: 580 a 630 g (con Raspberry Pi, placa, ventilador, motores y una batería de ~150 g).

MATERIAL DE CADA PIEZA
  Carcasa superior    PETG. Las 4 pestañas de clic se doblan cada vez que se abre; el PLA se quiebra antes.
  Carcasa inferior    PETG (o PLA si no hay PETG). El PETG aguanta mejor el calor de la Raspberry Pi.
  Ruedas motrices     PETG. El cubo entra a presión en el eje y el PLA puede rajarse.
  Aro de la bola      PETG. Los dos pines partidos tienen que flexionar.
  Bola                Canica de vidrio. Si se imprime, PLA: es el más duro y el que menos roza.
  ABS                 Solo con impresora cerrada: una pieza de 215 mm se despega y se tuerce al aire libre.
                      Es el más liviano (todo impreso pesaría unos 210 g en vez de 250 g).
  TPU (flex)          No para estas piezas: son rígidas o tienen encajes a presión. Solo serviría
                      para una llanta sobre la rueda motriz, en lugar de la liga.

COMPROBACIÓN CONTRA EL MOTOR (AD12672: 30 rpm a 6 V, 60 rpm a 12 V; par a rotor bloqueado 110 / 200 oz-in)
  Fuerza que hace falta para mover el robot      unos 2 N en total (rodadura, roce de la bola, rampas pequeñas).
  Fuerza que puede dar cada rueda de 30 mm       52 N a 6 V, 94 N a 12 V.
  El motor trabaja a un 2 % de su par máximo: el peso no es problema, sobra fuerza.
  Lo que sí limita:
    - Velocidad: 4.7 cm/s a 6 V y 9.4 cm/s a 12 V. Es un motor lento; una rueda más grande lo hace más rápido.
    - Agarre: la rueda de plástico lisa patina. Lleva un canal en V para ponerle una liga o un O-ring.

POR QUÉ LA RUEDA ES DE 30 mm Y NO DE 15 mm
  El motor mide 10 mm de alto. Apoyado sobre el piso de la carcasa, su eje queda a 7 mm de la cara de abajo.
  Una rueda de 15 mm (radio 7.5) dejaría la carcasa a 0.5 mm del suelo: rozaría. Con 30 mm queda a 8 mm.
  Para otro diámetro, cambiar WHEEL_D en carcasa_roomba.py: la ranura, la bola y la altura se ajustan solas.

CÓMO SE CIERRA Y SE ABRE
  La pieza superior baja por fuera de la pared de la inferior y se apoya en el borde del piso.
  Tiene 4 pestañas flexibles con un botón por dentro; al empujar la tapa, los 4 botones hacen clic
  en 4 agujeros de la pared inferior. Solo entra en una posición: la guía interna de la tapa va en la
  ranura del frente. Para abrir: sujetar el borde del piso por las dos muescas laterales y jalar la tapa.

DÓNDE VA CADA COSA (ver vistas/vista_1_distribucion.png)
  Motores           No tienen soporte: se colocan sobre el piso, junto a la ranura de cada rueda,
                    con el eje apuntando hacia afuera y centrado en la ranura.
                    El motor izquierdo queda debajo de la placa perforada.
  Ruedas motrices   Entran a presión en el eje en D del motor, con el cubo hacia el motor.
                    Poner una liga o un O-ring en el canal.
  Rueda de apoyo    Atrás. La bola se mete por debajo en el asiento cónico del piso y se tapa con el aro,
                    que entra a presión con sus dos pines. El aro se quita jalándolo.
  Placa perforada   Lado izquierdo, a lo largo. Se apoya en 4 esquinas, a 11 mm del piso
                    (elevada para que el motor izquierdo pase por debajo).
  Raspberry Pi 4    Lado derecho, a lo largo, sobre 4 espigas que entran en los agujeros de la placa.
                    Tarjeta SD hacia atrás, USB y Ethernet hacia el frente, USB-C hacia la derecha,
                    pines GPIO hacia la placa perforada.
  Ventilador        Marco al frente, sobre el agujero de entrada de aire. Entra a presión, soplando hacia arriba.
  Botón             Agujero de 16.2 mm en la tapa, al frente a la izquierda (en el centro no cabe:
                    debajo quedan la placa y la Raspberry Pi).
  Salida de aire    Rejilla en la tapa, encima del ventilador.
  Batería           Sin lugar asignado. Ponerla atrás (sobre la placa o junto a la rueda de apoyo) para que
                    el peso quede entre las ruedas motrices y la bola; si queda adelante, el robot cabecea.

VERSIÓN DE SUCCIÓN (carcasa_inferior_succion.stl + boquilla_succion.stl; imágenes vistas/succion_*.png)
  Usa la misma pieza superior, las mismas ruedas y la misma bola. Cambia solo la zona del ventilador:
  Boca de succión    Ranura de 70 x 12 mm en el piso, al frente (antes: un agujero redondo de 28 mm).
  Campana            Sobre la boca hay una campana de 72 x 29 mm que se va cerrando hasta el ventilador,
                     22 mm más arriba. El aire entra por todo el ancho de la boca y llega recogido al ventilador.
                     Detrás de la boca queda un piso con un reborde de 4 mm donde se asienta el polvo pesado.
  Ventilador         Va encima de la campana, en el mismo marco a presión, soplando hacia arriba.
                     Queda a 7 mm de la rejilla de la tapa.
  Boquilla           Pieza aparte que entra a presión por debajo, con dos pines. Baja la entrada de aire
                     de 8 mm a 2 mm del suelo, que es donde está el polvo. El frente queda 2 mm más alto
                     para que la basura pueda entrar. Sin la boquilla la succión en el suelo es mucho menor.
  Raspberry Pi       Va 4 mm más atrás que en la otra versión, para que los cables USB no topen con la campana.
  Filtro (opcional)  Se puede poner una malla fina debajo del ventilador, apretada por el mismo ventilador,
                     para que el polvo no pase por las aspas. Con este ventilador la malla quita bastante caudal.
  Peso               La pieza inferior pasa de 114 g a 124 g; la boquilla pesa 4 g.
  Límite real        El ventilador AD32862 es un cooler de 30 mm (5 V, 0.16 A). Esta versión le da la mejor
                     entrada de aire posible, pero levanta polvo liviano y pelusa, no migas ni arena.
                     Para aspirar más hace falta un ventilador tipo turbina (blower).

AJUSTES SI ALGO QUEDA FLOJO O APRETADO (valores al inicio de carcasa_roomba.py)
  Rueda floja o no entra en el eje   BORE_FIT.
  Pines del aro flojos o apretados   PIN_D.
  Cierre muy duro o muy flojo        BUMP_OUT y TAB_L.
  Tapa no entra en la inferior       FIT.

SUPUESTOS QUE HAY QUE CONFIRMAR CON LAS PIEZAS EN MANO
  - Eje del motor: 3 mm en D (2.5 mm sobre el plano) y 10 mm de largo.
  - Alto del motor: 10 mm. Si el motor queda más alto o más bajo que apoyado en el piso,
    la carcasa queda inclinada; se corrige cambiando WHEEL_D.
  - Diámetro de la canica: 16 mm (las hay de 14 a 17 mm). Menos de 15 mm se sale por el aro.
  - Diámetro del botón (16 mm).

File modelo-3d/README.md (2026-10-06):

# Modelo 3D de la carcasa

Carcasa circular de 215 mm en dos piezas que cierran a presión, con sus tres ruedas.
El detalle del diseño está en [`../docs/hardware-chasis.md`](../docs/hardware-chasis.md)
y las notas originales, con los ajustes de impresión, en [`LEEME.txt`](LEEME.txt).

| Archivo | Qué es |
|---|---|
| `carcasa_roomba.py` | Modelo paramétrico en CadQuery. `python carcasa_roomba.py` regenera todas las piezas |
| `carcasa_inferior_succion.stl` | Pieza de abajo que lleva el robot, con la campana de succión |
| `boquilla_succion.stl` | Boquilla que entra a presión por debajo |
| `carcasa_inferior.stl` | Variante de la pieza de abajo sin campana; no es la que se usó |
| `carcasa_superior.stl` | Pieza de arriba, con las pestañas de clic |
| `rueda_motriz_x2.stl` | Rueda motriz de 30 mm; se imprimen dos |
| `rueda_apoyo_aro.stl`, `rueda_apoyo_bola_16mm.stl` | Aro y bola de la rueda de apoyo |
| `*.step` | Las mismas piezas para editar en un programa CAD |
| `vistas/` | Imágenes del diseño |

Carcasa armada

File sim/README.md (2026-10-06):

# `sim/` — Simulador de hardware para probar en la laptop

Corre la biblioteca de control **sin la Raspberry Pi**. Sustituye a `pigpiod`
por una implementación falsa que mueve un robot virtual dentro de una sala de
4×4 m con muebles, y responde el hardware midiendo sobre ese mundo: el servo del
radar, el HC-SR04 que mide hacia donde apunta el servo y el MPU-6050 por I2C.
Sirve para dos cosas:

- **probar `librobot` de verdad** (no solo compilarla) mientras no está el kit;
- **plan B para la demo** si el hardware falla el día de la presentación.

## Cómo se conecta sin tocar `lib/`

Los fuentes de `lib/` quedan intactos. El truco está en el include:

```
lib_motors.c  →  #include <pigpiod_if2.h>
```

`construir.sh` compila con `-I.`, así que ese `#include` resuelve contra el
`pigpiod_if2.h` de esta carpeta —el del simulador— en vez del real. El enlace
usa `pigpio_sim.c`, que traduce cada escritura de pin a un movimiento del robot
virtual (`mundo.c`). El mismo código que corre en la Pi corre aquí.

## Uso

```sh
cd sim
./construir.sh          # compila con gcc del host, no necesita Yocto
./prueba_librobot       # ejercita cada módulo y compara contra el mundo real
```

Devuelve 0 si todas las comprobaciones pasan, e imprime al final el recorrido
del robot dibujado en la terminal.

Para el binario ARM bajo `qemu-aarch64` (`construir_arm.sh`) y el servidor
completo (`construir_servidor.sh` + `prueba_api.sh`), ver
[`../docs/qemu.md`](../docs/qemu.md) y
[`../docs/evidencias/`](../docs/evidencias/).

## Qué comprueba `prueba_librobot` (issue #19) — 47 comprobaciones

| Módulo | Verificación |
|---|---|
| Arranque | `robot_init()` abre la sesión, el MPU-6050 contesta en el bus I2C |
| MPU-6050 | la calibración quita el sesgo de fábrica del sensor simulado (0.02 g y 1.5 °/s); el eje vertical mide 1 g; la odometría lo usa |
| Radar | completa un barrido; cada uno de los 7 ángulos mide lo que hay en el mundo en esa dirección; las distancias de la fachada son los ángulos 90/180/0; `radar_rayo()` proyecta el eco frontal sobre la pared |
| Servo | pulsos de 1000 µs a 45°, saturación en 500 y 2500 µs, estimación del tiempo de viaje |
| LEDs | encender y apagar cada indicador cambia su estado |
| Motores básicos | avanzar, retroceder y girar mueven al robot como se espera |
| Control diferencial | `motores_set` satura en ±255; con velocidad fija (la que usa el robot) cualquier velocidad va al máximo y `motores_curva` gira sobre el eje, una llanta adelante y la otra atrás; con `-DMOTOR_VELOCIDAD_VARIABLE=1`, velocidades distintas describen una curva y `motores_curva(v,100)` detiene la llanta interior |
| Velocidad (MPU) | al arrancar sigue la inercia real mejor que el modelo de motores; en crucero queda a ±15 % de la real; detenido vuelve a 0 (ZUPT) |
| Tiempo de choque | detecta la pared al frente, coincide con el real a ±15 %, la cuenta regresiva baja entre lecturas y se anula al detenerse |
| Odometría | tras un recorrido en L, error de posición bajo el 20 % (medido: 1–5 %) y de rumbo bajo 5° (medido: 1–2°) |
| Audio | API: volumen, estado, listado (si hay tarjeta de sonido) |
| Cierre | `robot_shutdown()` cierra la sesión, deja los motores detenidos, el servo sin pulsos y el I2C libre |

## Piezas

| Archivo | Qué es |
|---|---|
| `pigpiod_if2.h` | Cabecera de reemplazo: el subconjunto de la API de pigpio que usa `librobot` (GPIO, PWM, servo, I2C) |
| `pigpio_sim.c` | Implementación falsa: pines → movimiento; servo que viaja a 600°/s; HC-SR04 que mide hacia donde apunta el servo; MPU-6050 en `/dev/i2c-1` que arranca dormido y trae sesgo |
| `mundo.h` / `mundo.c` | El robot virtual y la sala; avanza solo, al ritmo del reloj real, con inercia en las llantas. Avisa por `stderr` cada choque (`[sim] CHOQUE`) |
| `prueba_librobot.c` | El programa de prueba |
| `construir.sh` | Compila todo con el gcc del host |
| `construir_arm.sh` | Lo mismo con el Toolchain-SDK, y lo corre bajo `qemu-aarch64` |
| `construir_servidor.sh` / `prueba_api.sh` | El servidor completo sobre el simulador, y su prueba por HTTP |

## Límites

- El simulador **no** reproduce audio: prueba la biblioteca de control y el
  servidor. Para compilar en la laptop hacen falta las cabeceras de desarrollo
  de `libmicrohttpd`, `mpg123` y `alsa`.
- Los parámetros físicos del mundo (`REAL_VEL_MAX_CM_S`, `REAL_ENTRE_EJES_CM`)
  difieren a propósito de las constantes de `lib_odom`, para que las pruebas
  muestren el error que deja una calibración imperfecta.
- El HC-SR04 simulado mide a lo largo de un rayo: no tiene cono ni rebotes
  especulares. En la sala real habrá lecturas que el simulador no produce.

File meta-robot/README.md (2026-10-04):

# `meta-robot/` — Capa Yocto del proyecto

Capa propia que aporta todo lo que distingue la imagen del robot de una
`core-image-minimal`: la biblioteca dinámica, el servidor web, sus unidades systemd y
la configuración de WiFi, audio y kernel de la Raspberry Pi 4.

Compatible con **Poky `scarthgap`**.

## Contenido

| Directorio | Qué aporta |
|---|---|
| `conf/layer.conf` | Declaración de la capa: prioridad 10 y dependencias |
| `conf/local.conf.sample` | Bloque de configuración del proyecto para `build/conf/local.conf` |
| `recipes-image/images/` | `robot-image.bb` — la imagen final |
| `recipes-multimedia/librobot/` | `librobot_1.0.bb` — biblioteca dinámica de control |
| `recipes-robot/robot-server/` | `robot-server_1.0.bb` — servidor web + unidad systemd |
| `recipes-support/pigpio/` | `pigpio_1.0.bb` — acceso a GPIO y PWM por hardware |
| `recipes-audio/alsa-config/` | `asound.conf` — fuerza la salida PWM analógica (GPIO 18 → PAM8403) |
| `recipes-connectivity/wifi-config/` | WiFi preconfigurado para arranque headless |
| `recipes-bsp/bootfiles/` | `bbappend` de `config.txt` (audio por GPIO 18 con `audremap`, I2C) y `cmdline.txt` |
| `recipes-kernel/linux/` | Fragmento de configuración del kernel para el WiFi Broadcom |

## Dependencias

Declaradas en `LAYERDEPENDS_meta-robot`:

`core` · `raspberrypi` · `openembedded-layer` (meta-oe) · `multimedia-layer` · `networking-layer`

## Agregar la capa al build

```bash
bitbake-layers add-layer <ruta-del-repositorio>/meta-robot
bitbake-layers show-layers
```

> Agréguela **desde su ubicación dentro del repositorio clonado**. Las recetas
> `librobot` y `robot-server` toman sus fuentes de `lib/`, `server/` y `audio/` — que
> están en la raíz del repositorio — mediante `FILESEXTRAPATHS`. Si se copia solo esta
> carpeta a otro lado, el `do_fetch` falla.

El procedimiento completo está en [`../docs/yocto-setup.md`](../docs/yocto-setup.md).

## Antes del primer build

Cree el archivo de credenciales de WiFi a partir de la plantilla — el archivo real está
en `.gitignore` y nunca se sube al repositorio:

```bash
cp recipes-connectivity/wifi-config/files/wpa_supplicant-wlan0.conf.sample \
   recipes-connectivity/wifi-config/files/wpa_supplicant-wlan0.conf
```

Si se omite, la receta cae a la plantilla y la imagen se construye de todas formas, con
un `WARNING` de bitbake: el robot arranca pero no se conecta al WiFi. Es deliberado, para
que un clon limpio reproduzca la imagen sin pasos manuales previos.

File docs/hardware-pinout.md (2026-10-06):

# Mapa de pines GPIO

Referencia única del cableado. Cualquier cambio aquí **tiene que** reflejarse en el
código, y viceversa: los pines están escritos como `#define` en la biblioteca, y el
simulador (`sim/pigpio_sim.c`) los repite a propósito para que un cambio en un solo
lado se note.

Numeración **BCM** (la que usa pigpio), con el pin físico del conector de 40 pines.

---

## Tabla completa

| Función | BCM | Pin físico | Dirección | Definido en |
|---|---|---|---|---|
| **Motor derecho (salida A del L298N)** — vía optoacoplador; `ENA` con jumper ||||
| `IN1` — avance | 5 | 29 | Salida | `lib/lib_motors.c` |
| `IN2` — retroceso | 6 | 31 | Salida | `lib/lib_motors.c` |
| **Motor izquierdo (salida B del L298N)** — vía optoacoplador; `ENB` con jumper ||||
| `IN3` — avance | 23 | 16 | Salida | `lib/lib_motors.c` |
| `IN4` — retroceso | 24 | 18 | Salida | `lib/lib_motors.c` |
| **Radar: servo de 180°** — señal directa, alimentado de los 5 V de la Pi ||||
| Señal del servo (pulsos de 50 Hz) | 25 | 22 | Salida | `lib/lib_servo.h` |
| **Radar: HC-SR04 sobre el servo** ||||
| `TRIG` | 17 | 11 | Salida | `lib/lib_radar.h` |
| `ECHO` (con divisor 1k/2k) | 27 | 13 | Entrada | `lib/lib_radar.h` |
| **MPU-6050 (I2C-1)** ||||
| `SDA` | 2 | 3 | Bidireccional | `lib/lib_imu.h` (bus 1) |
| `SCL` | 3 | 5 | Salida | `lib/lib_imu.h` (bus 1) |
| `VCC` — 5 V (el GY-521 trae regulador de 3.3 V) | 5V | 2 | — | — |
| **Sensores IR de desnivel (opcional)** — módulos a 3.3 V, entradas con pull-down ||||
| Esquina delantera izquierda | 4 | 7 | Entrada | `lib/lib_caida.h` |
| Esquina delantera derecha | 8 | 24 | Entrada | `lib/lib_caida.h` |
| **LEDs indicadores** ||||
| Sistema encendido | 16 | 36 | Salida | `lib/lib_leds.h` |
| Modo autónomo | 20 | 38 | Salida | `lib/lib_leds.h` |
| Modo manual | 21 | 40 | Salida | `lib/lib_leds.h` |
| Obstáculo detectado | 26 | 37 | Salida | `lib/lib_leds.h` |
| **Audio** ||||
| PWM de audio → filtro RC → PAM8403 | 18 | 12 | Salida | `dtoverlay=audremap,pins_18_19` (`rpi-config_%.bbappend`) |
| Segundo canal PWM (misma señal, sin conectar) | 19 | 35 | Salida | ídem |

---

## Diagrama del conector

Solo los pines usados. `·` = pin libre.

```
                3V3  ( 1) ( 2)  5V ─── MPU VCC, servo, HC-SR04, PAM8403
      MPU SDA ─(GPIO2)( 3) ( 4)  5V
      MPU SCL ─(GPIO3)( 5) ( 6)  GND ────── GND lógica
     IR izq. ─(GPIO4)( 7) ( 8)  GPIO14  (UART TX, consola)
      MPU GND ─  GND ( 9) (10)  GPIO15  (UART RX, consola)
  TRIG radar ─(GPIO17)(11) (12)(GPIO18)─ audio PWM → PAM8403
  ECHO radar ─(GPIO27)(13) (14)  GND
            · GPIO22 (15) (16)(GPIO23)─ IN3 motor izq.
                 3V3 (17) (18)(GPIO24)─ IN4 motor izq.
            · GPIO10 (19) (20)  GND
            ·  GPIO9 (21) (22)(GPIO25)─ servo del radar
            · GPIO11 (23) (24)(GPIO8)─ IR der.
                 GND (25) (26)  GPIO7   ·
               ID_SD (27) (28)  ID_SC
 IN1 motor de─(GPIO5)(29) (30)  GND
 IN2 motor de─(GPIO6)(31) (32)  GPIO12  ·
            · GPIO13 (33) (34)  GND
2º canal audio (libre)(GPIO19)(35) (36)(GPIO16)─ LED encendido
LED obstáculo─(GPIO26)(37) (38)(GPIO20)─ LED autónomo
                 GND (39) (40)(GPIO21)─ LED manual
```

---

## Por qué estos pines

**Los motores se controlan solo con `IN1`–`IN4` (5, 6, 23 y 24).** El L298N lleva los
jumpers `ENA`/`ENB` puestos —siempre habilitado— y las entradas de sentido llevan
niveles fijos: los motores van siempre al máximo, sin PWM, por una desviación acordada
con el profesor (ver [`hardware-aislamiento.md`](hardware-aislamiento.md#velocidad-fija)).
El modo con PWM de la biblioteca usa esas mismas entradas, sin recablear. `GPIO 12` y
`13`, que llevaban `ENA`/`ENB`, quedan libres.

**GPIO 18 para el audio.** La salida PWM analógica que normalmente va al jack de 3.5 mm
se saca al conector con el overlay `audremap`, que acepta los pares 12/13 o 18/19. Se
eligió 18/19 cuando 12/13 eran el PWM de los motores, y se mantiene: ya está en la imagen
y en el cableado, y cambiarlo no aporta nada. Solo se cablea GPIO 18: la biblioteca mezcla
la música a mono y los dos canales llevan la misma señal (ver
[`hardware-sensores.md`](hardware-sensores.md)).

**GPIO 2 y 3 para el MPU-6050.** Son el bus I2C-1 del SoC (`/dev/i2c-1`) y traen
resistencias pull-up de 1.8 kΩ a 3.3 V en la propia placa. Estaban reservados
justamente "por si se agrega un sensor adicional".

**GPIO 25 para el servo.** Queda en el pin 22, al lado de `IN3`/`IN4` (16 y 18): las
señales de control quedan cerca. La del servo va directo al servo; las de los motores,
a la placa de optoacopladores.

**GPIO 17 y 27 para el HC-SR04 del radar.** Son los del antiguo sensor frontal: el
cable al borde delantero del chasis no cambia. Los pines de los dos sensores laterales
que ya no existen (22, 10, 9 y 11) quedan libres.

**LEDs en 16, 20, 21 y 26.** Bloque contiguo al final del conector, lejos de las señales
de motor. Reduce el acople de ruido de conmutación del PWM hacia las señales lógicas.

---

## Restricciones eléctricas

| Límite | Valor | Consecuencia |
|---|---|---|
| Corriente por GPIO | 16 mA | Nunca conectar un LED sin resistencia limitadora |
| Corriente total de todos los GPIO | 50 mA | Ver el presupuesto de abajo |
| Tensión de entrada de un GPIO | **3.3 V máximo** | El `ECHO` del HC-SR04 saca 5 V: **va con divisor obligatorio**. El MPU-6050 se alimenta a 5 V por el regulador de su módulo; SDA/SCL deben medirse en 3.3 V — ver [`hardware-sensores.md`](hardware-sensores.md) |
| Tensión de salida de un GPIO | 3.3 V | Los optoacopladores y el filtro de audio se dimensionan para esa tensión |

### Presupuesto de corriente del conector

Lo que los GPIO entregan desde su propio riel de 3.3 V, en el peor caso **simultáneo**:

| Consumidor | Peor caso | Por qué |
|---|---|---|
| 4 optoacopladores de motor a 5 mA | 20 mA | Con la inversión del opto compensada, el robot **detenido** (las cuatro entradas del L298N en bajo) es el caso con los cuatro LED internos encendidos |
| Señal del servo | < 1 mA | Entrada de alta impedancia; solo durante el pulso |
| LEDs indicadores a 5 mA | 15 mA | Como mucho **tres** encendidos: autónomo y manual son excluyentes |
| Filtro RC del audio | 0.6 mA | 3.3 V sobre 4.7 kΩ + 1 kΩ |
| `TRIG` del HC-SR04 | ≈ 0 | Entrada de alta impedancia del sensor |
| SDA/SCL | 0 | Colector abierto: el GPIO solo drena la corriente del pull-up |
| **Total** | **≈ 37 mA** | Dentro de los 50 mA, con 13 mA de margen |

Sin `ENA`/`ENB` hay dos optoacopladores menos que antes. Y autónomo y manual nunca están
encendidos juntos, así que los LEDs suman tres, no cuatro.
El `VCC` del MPU-6050, del servo, del HC-SR04 y del amplificador sale del pin de 5 V, no
de un GPIO, y no entra en esta cuenta.

> Meter 5 V a un GPIO destruye el pin, y a veces el SoC completo. No hay protección
> interna. Es el error que más Raspberry Pi mata en este tipo de proyecto.

---

## Pines deliberadamente libres

| Pin | Motivo |
|---|---|
| GPIO 14, 15 (UART) | Consola serie de depuración. `ENABLE_UART = "1"` en `local.conf` |
| GPIO 12, 13 | Liberados al dejar `ENA`/`ENB` con jumper. Son un par de PWM por hardware: sirven para un segundo servo o para pasar el audio a `pins_12_13` |
| GPIO 19 | Toma la función PWM de audio con `audremap`; no se conecta, pero tampoco se reutiliza |
| GPIO 22, 10, 9, 11 | Liberados por los sensores laterales. El profesor aceptó el radar junto con el MPU-6050, así que no se montó un segundo HC-SR04; habría ido en 22 (`TRIG`) y 10 (`ECHO`) |
| GPIO 7 | Margen; 4 y 8 llevan los sensores de desnivel. SPI no está habilitado, así que 7 y 8 son GPIO comunes |

---

## Verificación del cableado

Antes de energizar, con la Raspberry Pi **apagada y desconectada**, verificar con el
multímetro en modo continuidad que cada pin del conector llega a donde dice la tabla.
Un cable cruzado entre una señal de motor y una entrada de sensor puede meter 5 V a un
GPIO configurado como salida.

Con el sistema encendido, el propio servidor confirma lo que encontró:

```bash
journalctl -u robot-server | grep -E "imu|radar|leds"
#   [imu] MPU-6050 listo en /dev/i2c-1, direccion 0x68
#   [imu] calibrado con 100 muestras: sesgo ...
#   [radar] barriendo de 0 a 180 grados en pasos de 30
ls /dev/i2c-1                    # el bus existe: dtparam=i2c_arm=on + i2c-dev
```

Para probar un pin a mano hace falta `pigs`, que **no** va en la imagen de entrega. En
desarrollo se agrega con `IMAGE_INSTALL:append = " pigpio-bin-pigs"` en `local.conf`:

```bash
pigs modes 16 w ; pigs w 16 1 ; sleep 1 ; pigs w 16 0   # un LED
pigs s 25 1500 ; sleep 1 ; pigs s 25 0                   # servo al frente y suelto
pigs i2co 1 0x68 0                                       # abre el MPU: devuelve un handle h
pigs i2crb 0 0x75                                        # WHO_AM_I con h = 0: 104 (0x68)
pigs i2cc 0                                              # cierra el handle
```

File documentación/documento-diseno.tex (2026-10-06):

% ---------------------------------------------------------------------------
% Proyecto I - Robot Aspiradora Autonomo (Yocto)
% CE-1113 Sistemas Empotrados - TEC
%
% Documento de Diseno (DI): indicadores DI1 a DI4 del enunciado.
% El detalle tecnico (calculos, listas de materiales, procedimientos) vive en
% docs/; aqui se resume y se cita.
%
% Compilar:  pdflatex documento-diseno.tex   (dos veces)
% ---------------------------------------------------------------------------
\documentclass[11pt,a4paper]{article}

\usepackage[T1]{fontenc}
\usepackage[utf8]{inputenc}
\usepackage{lmodern}
\usepackage[spanish,es-noshorthands,es-noquoting]{babel}
\usepackage[margin=2.4cm]{geometry}
\usepackage{tikz}
\usepackage{amsmath}
\usepackage{amssymb}
\usepackage{booktabs}
\usepackage{tabularx}
\usepackage{longtable}
\usepackage{array}
\usepackage{enumitem}
\usepackage{caption}
\PassOptionsToPackage{hyphens}{url}
\usepackage[hidelinks]{hyperref}

\usetikzlibrary{positioning,arrows.meta,fit,backgrounds,calc}

\captionsetup{font=small,labelfont=bf,width=.92\linewidth}
\setlength{\parskip}{0.45em}
\setlength{\parindent}{0pt}
\emergencystretch=4em
\setlist{itemsep=1pt,topsep=2pt}
\renewcommand{\arraystretch}{1.18}

% --- paleta (la misma de hardware-diagramas.tex) ----------------------------
\definecolor{cLog}{RGB}{31,102,168}
\definecolor{cPot}{RGB}{193,84,26}
\definecolor{cGris}{RGB}{120,120,120}
\definecolor{cFondo}{RGB}{245,247,250}
\definecolor{cPend}{RGB}{176,32,32}

\tikzset{
  blk/.style   ={draw,rounded corners=2pt,align=center,inner sep=4pt,
                 minimum height=9mm,font=\small},
  blkl/.style  ={blk,draw=cLog,fill=cLog!8},
  blkp/.style  ={blk,draw=cPot,fill=cPot!8},
  blkn/.style  ={blk,draw=cGris,fill=black!3},
  ln/.style    ={-{Latex[length=2mm]},thick},
}

% --- utilidades -------------------------------------------------------------
% Identificadores y rutas con guion bajo, sin escaparlos a mano.
\newcommand{\id}[1]{\texttt{\detokenize{#1}}}
% Rutas largas en celdas angostas: \path corta en / y en guiones.
\newcommand{\ruta}{\path}
% Dato que el grupo debe completar antes de entregar. Buscar "PENDIENTE".
\newcommand{\pendiente}[1]{\textcolor{cPend}{\textbf{[PENDIENTE: #1]}}}
\newcolumntype{L}[1]{>{\raggedright\arraybackslash}p{#1}}
\newcolumntype{C}[1]{>{\centering\arraybackslash}p{#1}}
\newcolumntype{Y}{>{\raggedright\arraybackslash}X}

\newsavebox{\notabox}
\newenvironment{nota}
  {\par\medskip\begin{lrbox}{\notabox}%
   \begin{minipage}{\dimexpr0.95\linewidth-14pt\relax}\small}
  {\end{minipage}\end{lrbox}%
   \begin{center}\setlength{\fboxsep}{7pt}\colorbox{cFondo}{\usebox{\notabox}}\end{center}\medskip}

% ---------------------------------------------------------------------------
\begin{document}

\begin{titlepage}
\centering
{\large\bfseries Instituto Tecnológico de Costa Rica\par}
\vspace{0.3cm}
{\large Escuela de Ingeniería en Computadores\par}
\vspace{0.3cm}
{\large CE-1113 Sistemas Empotrados\par}
\vspace{3.2cm}
{\LARGE\bfseries Documento de Diseño (DI)\par}
\vspace{0.6cm}
{\Large Proyecto I --- Sistema embebido a la medida para un robot aspiradora
autónomo con reproducción de audio y control remoto\par}
\vspace{3.2cm}
{\large\bfseries Integrantes\par}
\vspace{0.2cm}
{\large
\begin{tabular}{ll}
Randall Bolaños López & 2019043784 \\
Aldo Alessandro Bagliano Gómez & 2020018456 \\
Yendry Badilla Gutierrez & 2016113047 \\
Christopher David Rodriguez Cordero & 2022040771 \\
\end{tabular}\par}
\vspace{1.6cm}
{\large\bfseries Profesor\par}
\vspace{0.2cm}
{\large Dr.-Ing. Jeferson González Gómez\par}
\vfill
{\large Octubre de 2026\par}
\end{titlepage}

\tableofcontents
\newpage

% ===========================================================================
\section{Introducción}

Este documento evidencia el atributo de \textbf{Diseño (DI)} en el Proyecto I
del curso. Recorre el proceso completo: qué se necesitaba y bajo qué
restricciones (DI1), qué alternativas se valoraron y con qué criterios (DI2),
cómo quedó diseñada la alternativa elegida (DI3) y cómo se comprobó que el
resultado cumple los requerimientos y las consideraciones de seguridad, costo
e impacto (DI4).

El producto es un robot aspiradora de tracción diferencial sobre una
Raspberry Pi 4 con una imagen de Linux mínima construida con Yocto (Poky,
rama \id{scarthgap}). Navega de forma autónoma evadiendo obstáculos, reproduce
MP3 y se opera desde un panel web que muestra la telemetría y el mapa de
recorrido en tiempo real. Todo acceso al hardware pasa por una biblioteca
dinámica propia, \id{librobot.so}, compilada de forma cruzada.

El detalle técnico ---cálculos, listas de materiales, procedimientos de
verificación y evidencias--- está en la carpeta \id{docs/} del repositorio.
Aquí se resume y se cita el archivo correspondiente.

% ===========================================================================
\section{DI1 --- Necesidades y requerimientos}

\subsection{El problema}

Un robot de limpieza coordina en tiempo real subsistemas que compiten por los
mismos recursos: sensado de proximidad, tracción, audio, red e interfaz de
usuario. El problema es complejo por tres razones que no se pueden resolver
por separado:

\begin{itemize}
  \item \textbf{Recursos acotados.} El enunciado fija un presupuesto de
        200\,MB de sistema de archivos raíz y 15\,s de arranque. Los GPIO
        entregan 16\,mA por pin y 50\,mA en total, y no toleran más de
        3.3\,V.
  \item \textbf{Dominios eléctricos incompatibles.} La lógica trabaja a
        3.3\,V y miliamperios; los motores, a 9\,V con picos de varias
        veces su corriente nominal. Deben convivir sin compartir tierra.
  \item \textbf{Concurrencia.} Navegar, medir, reproducir audio y atender la
        interfaz ocurren a la vez, y ninguna tarea puede degradar la
        respuesta ante un obstáculo.
\end{itemize}

\subsection{Partes interesadas y sus necesidades}

\begin{center}
\begin{tabularx}{\linewidth}{L{3.1cm}Y}
\toprule
\textbf{Parte interesada} & \textbf{Necesidad} \\
\midrule
Usuario final & Un robot que limpie sin supervisión, que se pueda tomar a
mano desde el celular y cuyo estado se entienda de un vistazo (LEDs, sonidos,
mapa). \\
Curso y profesor & Cumplimiento verificable del enunciado, y que el equipo
prestado (Raspberry Pi 4 y su kit) regrese sin daño. \\
Grupo de trabajo & Un diseño que cuatro personas puedan construir en seis
semanas, con el inventario disponible y un costo que el grupo pueda asumir. \\
Terceros en el entorno & Que el robot no represente un riesgo: ni eléctrico,
ni de incendio, ni por golpear a personas u objetos, ni por exponer la red. \\
\bottomrule
\end{tabularx}
\end{center}

\subsection{Requerimientos técnicos}

Los requerimientos obligatorios del enunciado se numeran para trazarlos
después en la validación (sección~\ref{sec:matriz}).

\begin{longtable}{L{1.2cm}L{3.6cm}L{10.2cm}}
\toprule
\textbf{Id.} & \textbf{Área} & \textbf{Requerimiento} \\
\midrule
\endhead
R1 & Navegación & Modo autónomo con al menos un algoritmo de cobertura
reactiva. Ante un obstáculo: detenerse, retroceder y cambiar de dirección. \\
R2 & Sensado & Al menos dos sensores de proximidad para detección frontal y
lateral, leídos y procesados en tiempo real. \\
R3 & Tracción & Dos motores DC con control diferencial (avance, retroceso,
giros, detención) y velocidad por PWM para giros de radio variable. \\
R4 & Indicadores & Cuatro LEDs: modo autónomo, modo manual, obstáculo y
sistema encendido. \\
R5 & Audio & Reproducir MP3 locales de forma concurrente con la navegación. \\
R6 & Audio & Desde la interfaz: elegir canción, reproducir, pausar, detener y
ajustar el volumen. \\
R7 & Audio & Salida directa desde el robot, con parlante a bordo. \\
R8 & Audio & Sonidos de notificación en cuatro eventos: inicio del sistema,
inicio del modo autónomo, obstáculo y cambio a manual. \\
R9 & Control remoto & Conmutar entre modo autónomo y manual; en manual, los
controles direccionales mandan los motores. \\
R10 & Control remoto & Panel con modo activo, controles, sensores en tiempo
real, control de audio, estado de los LEDs y mapa. \\
R11 & Mapa & Grilla 2D incremental (visitada, obstáculo, desconocida) a
partir de los sensores y la odometría, visible en tiempo real. \\
R12 & Seguridad & Pantalla de inicio de sesión con al menos un usuario y un
protocolo de seguridad mínimo. \\
R13 & Arranque & Inicio automático con una unidad \id{systemd} propia,
\id{Restart=on-failure} y sin interfaz gráfica local. \\
R14 & Biblioteca & Biblioteca dinámica propia que encapsule motores, sensores,
LEDs y audio; el servidor la usa de forma exclusiva. \\
R15 & Desarrollo & Todo el software se compila de forma cruzada en el host. \\
R16 & Sistema operativo & Imagen mínima con Yocto, solo con los paquetes
necesarios y cada uno justificado. \\
R17 & Construcción & CMake o Autotools, generando el paquete estándar. \\
R18 & Receta & Al menos una receta \id{.bb} propia; la imagen se reproduce
con \id{bitbake <imagen>} sin pasos manuales. \\
R19 & Eficiencia & Medir y reportar rootfs, tiempo de arranque, RAM y CPU en
operación normal. Referencia: rootfs $\leq$ 200\,MB y arranque $\leq$ 15\,s. \\
\bottomrule
\end{longtable}

Se implementaron además los tres requerimientos opcionales:

\begin{itemize}
  \item \textbf{RO1, desnivel.} Dos sensores infrarrojos al piso en las
        esquinas delanteras (GPIO 4 y 8) detienen el robot ante el borde de
        una grada; en autónomo retrocede y gira hacia el otro lado, y en
        manual no deja avanzar.
  \item \textbf{RO2, fin de ciclo.} El usuario fija una meta en minutos de
        modo autónomo o en metros cuadrados recorridos; al cumplirla el robot
        se detiene, suena un aviso y el panel lo informa.
  \item \textbf{RO3, playlist persistente.} La lista se edita desde el panel
        y se guarda en la partición de la música, así sobrevive a los
        reinicios.
\end{itemize}

\subsection{Salud y seguridad pública}

\begin{center}
\begin{tabularx}{\linewidth}{L{3.6cm}Y}
\toprule
\textbf{Riesgo} & \textbf{Requerimiento que se deriva} \\
\midrule
Incendio o fuga térmica de una celda de Li-Ion & Toda celda de Li-Ion debe
llevar protección de sobrecarga, sobredescarga y cortocircuito; nunca
alimentar la Raspberry directo de la celda. \\
Daño al equipo prestado & Aislamiento óptico entre la lógica y la etapa de
potencia, con tierras separadas; ninguna señal de 5\,V llega a un GPIO. \\
Golpes a personas u objetos & Freno automático ante un obstáculo también en
modo manual; masa menor a 1.5\,kg; los motores quedan frenados en reposo y
durante el arranque. \\
Cables en las llantas & Ruteo fijo del cableado, sin tramos sueltos a menos
de 1\,cm de una llanta. \\
Acceso no autorizado por la red & Inicio de sesión obligatorio; el demonio
de GPIO solo escucha en la interfaz local. \\
Nivel sonoro & Volumen ajustable desde la interfaz y potencia máxima acotada
por el divisor de entrada del amplificador. \\
\bottomrule
\end{tabularx}
\end{center}

\subsection{Costos}

La Raspberry Pi 4 y su kit los presta el curso, de modo que el costo para el
grupo es el del modelo físico. La compra se planeó con una estimación por
bloques:

\begin{center}
\begin{tabular}{L{6.6cm}C{3.2cm}}
\toprule
\textbf{Bloque} & \textbf{Estimación (USD)} \\
\midrule
Alimentación portátil (baterías, protección y regulación) & 25--45 \\
Circuitería y sensores (optoacopladores, servo, pasivos, placas) & 9--17 \\
Etapa de audio (PAM8403, parlante, filtro) & 5--12 \\
Chasis y acabado & 10--25 \\
\midrule
\textbf{Total del robot} & \textbf{49--99} \\
\bottomrule
\end{tabular}
\end{center}

El requerimiento que se fijó fue mantenerse dentro de ese intervalo y
aprovechar primero lo que el grupo ya tenía: un sensor ultrasónico, un
MPU-6050 y un driver L298N.

El gasto real del grupo fue el siguiente. Las compras se hicieron en
colones y se expresan en dólares a un tipo de cambio aproximado de 500
colones por dólar:

\begin{center}
\begin{tabular}{L{9.4cm}C{3.2cm}}
\toprule
\textbf{Gasto} & \textbf{Costo (USD)} \\
\midrule
Dos motores y un ventilador del primer diseño, que se descartaron al
rehacerlo & 24 \\
Dos motores para el diseño final, los que lleva el robot & 16 \\
Impresión 3D de las piezas del robot & 50 \\
Aspiradora robot usada, para hacerle ingeniería inversa & 20 \\
Optoacopladores, placas y otros componentes & 10 \\
Otros gastos relacionados & 14 \\
\midrule
\textbf{Total} & \textbf{134} \\
\bottomrule
\end{tabular}
\end{center}

De ese total, 90 USD quedaron en el robot (motores, impresión 3D,
circuitería y otros gastos) y 44 USD fueron costo de aprendizaje: los
motores y el ventilador del primer diseño, que se dejaron de usar cuando el
diseño se rehízo, y la aspiradora que se desarmó para estudiarla. La
comparación con la estimación está en la sección~\ref{sec:costo}.

\subsection{Impacto ambiental}

\begin{itemize}
  \item \textbf{Baterías.} Son el componente de mayor impacto. Se prefieren
        recargables, deben poder desmontarse, y al final de su vida se
        entregan a un gestor de residuos electrónicos.
  \item \textbf{Residuos electrónicos.} El montaje debe permitir reutilizar
        los módulos: conectores desconectables y nada pegado de forma
        permanente a la Raspberry Pi, que se devuelve al curso.
  \item \textbf{Consumo.} Menos consumo es más autonomía con las mismas
        baterías: se prefiere amplificación clase D y un sistema operativo
        sin servicios de más.
  \item \textbf{Compras.} Reutilizar el inventario del grupo antes que
        comprar componentes nuevos.
\end{itemize}

\subsection{Recursos disponibles y restricciones}

\begin{center}
\begin{tabularx}{\linewidth}{L{3.6cm}Y}
\toprule
\textbf{Recurso} & \textbf{Disponibilidad} \\
\midrule
Plataforma & Raspberry Pi 4 y kit, prestados por el curso. \\
Inventario del grupo & Un HC-SR04, un MPU-6050 (módulo GY-521) y un driver
L298N de doble puente. \\
Personas y tiempo & Cuatro integrantes, del 25 de agosto al 6 de octubre de
2026. \\
Host de construcción & Laptop de 4 núcleos y 7\,GB de RAM, por debajo de lo
recomendado para Yocto. \\
Software de partida & Un proyecto de referencia con licencia MIT, del que
derivan parte de la capa y del código (atribuido en \id{NOTICE.md}). \\
Herramientas & Multímetro, cautín, y el Toolchain-SDK generado por el propio
proyecto. \\
\bottomrule
\end{tabularx}
\end{center}

De ahí salen dos restricciones que marcaron el diseño: el hardware llegó
tarde respecto del software, así que hacía falta poder desarrollar y probar
sin él; y el host de construcción era el cuello de botella de cada iteración
de la imagen.

% ===========================================================================
\section{DI2 --- Valoración de alternativas}

\subsection{Método}

Las decisiones de mayor peso se evaluaron con una matriz ponderada. Cada
alternativa recibe una nota de 1 (peor) a 5 (mejor) en cuatro factores:

\begin{center}
\begin{tabularx}{\linewidth}{L{2.4cm}C{1.4cm}Y}
\toprule
\textbf{Factor} & \textbf{Peso} & \textbf{Qué mide} \\
\midrule
Técnico & 40\,\% & Cumplimiento del requerimiento, desempeño, uso de GPIO y
riesgo de integración. \\
Económico & 25\,\% & Costo de compra y disponibilidad local; cuánto del
inventario se aprovecha. \\
Ambiental & 15\,\% & Cantidad de componentes, consumo y reutilización. \\
Social & 20\,\% & Seguridad de las personas y del equipo prestado. \\
\bottomrule
\end{tabularx}
\end{center}

El factor técnico pesa más porque una alternativa que no cumple el
requerimiento no es una alternativa. El social pesa más que el ambiental
porque el enunciado hace al grupo responsable del equipo prestado.

\subsection{Detección de obstáculos}

\begin{center}
\begin{tabularx}{\linewidth}{Y C{1.25cm}C{1.4cm}C{1.4cm}C{1.1cm}C{1.2cm}}
\toprule
\textbf{Alternativa} & \textbf{Téc.} & \textbf{Econ.} & \textbf{Amb.} &
\textbf{Soc.} & \textbf{Total} \\
\midrule
Tres HC-SR04 fijos & 3 & 3 & 3 & 4 & 3.20 \\
\textbf{Un HC-SR04 sobre un servo (radar)} & 4 & 4 & 4 & 3 & \textbf{3.80} \\
Sensores infrarrojos & 2 & 4 & 3 & 2 & 2.65 \\
\bottomrule
\end{tabularx}
\end{center}

Los tres sensores fijos dan una lectura frontal rápida ($\approx$ 16\,Hz),
pero solo tres direcciones, ocupan seis GPIO, obligan a secuenciar los
disparos para evitar ecos cruzados y exigían comprar dos sensores más. Los
infrarrojos económicos tienen poco alcance, dependen del color de la
superficie y de la luz ambiente, y no entregan una distancia útil para el
mapa.

El radar mide siete direcciones con tres GPIO y el sensor que el grupo ya
tenía. Su debilidad es que mira al frente una vez cada 1.2\,s; por eso su
nota social es menor. Esa debilidad se atacó en el diseño con la estimación
del tiempo antes de chocar (sección~\ref{sec:creativo}).

\subsection{Alimentación}

\begin{center}
\begin{tabularx}{\linewidth}{Y C{1.25cm}C{1.4cm}C{1.4cm}C{1.1cm}C{1.2cm}}
\toprule
\textbf{Alternativa} & \textbf{Téc.} & \textbf{Econ.} & \textbf{Amb.} &
\textbf{Soc.} & \textbf{Total} \\
\midrule
Una celda (1S) con elevador a 5\,V & 2 & 4 & 4 & 2 & 2.80 \\
Pack 2S de Li-Ion con BMS y reductores & 3 & 3 & 4 & 3 & 3.15 \\
\textbf{Power bank USB y baterías de 9\,V para los motores} & 4 & 4 & 2 & 5 &
\textbf{3.90} \\
\bottomrule
\end{tabularx}
\end{center}

Con una celda, entregar 15\,W a 5\,V pide cerca de 4.5\,A de entrada, y más
de 5\,A con la celda descargada: los elevadores MT3608 y XL6009 no lo
sostienen, y una caída de tensión corrompe la microSD.

El pack 2S alimenta todo desde una sola fuente y es recargable, pero obliga
al grupo a armar y ajustar el BMS, el fusible y dos reductores antes de
conectar un equipo prestado. Además, los reductores comunes no son aislados:
con los dos rieles colgando del mismo pack, las tierras de la lógica y de los
motores quedan unidas por el retorno, que es justo lo que el enunciado pide
evitar.

El power bank entrega 5\,V ya regulados y trae de fábrica la protección de su
celda. Con las baterías de los motores aparte, los dos dominios no comparten
ningún conductor y la separación de tierras viene dada por la propia fuente.
Las baterías de 9\,V se consiguen en cualquier comercio. Su debilidad es
ambiental y de autonomía: son alcalinas desechables y de poca capacidad, y
por eso esa alternativa tiene la nota ambiental más baja.

\subsection{Salida de audio}

\begin{center}
\begin{tabularx}{\linewidth}{Y C{1.25cm}C{1.4cm}C{1.4cm}C{1.1cm}C{1.2cm}}
\toprule
\textbf{Alternativa} & \textbf{Téc.} & \textbf{Econ.} & \textbf{Amb.} &
\textbf{Soc.} & \textbf{Total} \\
\midrule
Jack de 3.5\,mm con LM386 & 3 & 4 & 3 & 3 & 3.25 \\
\textbf{PWM por GPIO 18 con PAM8403} & 4 & 5 & 4 & 4 & \textbf{4.25} \\
DAC I2S (MAX98357A) & 4 & 3 & 4 & 4 & 3.75 \\
\bottomrule
\end{tabularx}
\end{center}

El LM386 es clase AB, rinde cerca del 50\,\% y pide ocho componentes
discretos para dar 0.5\,W. El DAC I2S da el mejor audio, pero es más caro,
más difícil de conseguir localmente y cambia la configuración de ALSA. El
PAM8403 es un módulo armado, clase D ($\approx$ 85\,\%), que entrega 1.3\,W
sobre 8\,$\Omega$ con un filtro de tres pasivos.

\subsection{Odometría}

\begin{center}
\begin{tabularx}{\linewidth}{Y C{1.25cm}C{1.4cm}C{1.4cm}C{1.1cm}C{1.2cm}}
\toprule
\textbf{Alternativa} & \textbf{Téc.} & \textbf{Econ.} & \textbf{Amb.} &
\textbf{Soc.} & \textbf{Total} \\
\midrule
Solo el modelo de los motores & 2 & 5 & 5 & 3 & 3.40 \\
Encoders ópticos de rueda & 4 & 3 & 3 & 3 & 3.40 \\
\textbf{MPU-6050 fusionado con el modelo} & 4 & 5 & 5 & 4 & \textbf{4.40} \\
\bottomrule
\end{tabularx}
\end{center}

Estimar la posición solo con el tiempo y el ciclo de trabajo deja derivar el
rumbo en cuanto las dos llantas giran distinto, y el rumbo es lo que más
deforma el mapa. Los encoders miden bien la distancia, pero había que
comprarlos y montarlos en motores que no traen eje para ello. El MPU-6050 ya
estaba en el inventario: su giroscopio da el rumbo y su acelerómetro la
dinámica de la velocidad, que además habilita el tiempo antes de chocar.

\subsection{Otras decisiones}

\begin{longtable}{L{2.6cm}L{3.8cm}L{8.6cm}}
\toprule
\textbf{Decisión} & \textbf{Elegida} & \textbf{Alternativas y motivo} \\
\midrule
\endhead
Aislamiento & Cuatro PC817 & El DRV8871 acepta 3.3\,V pero comparte tierra:
no aísla y se descartó. El ADuM1401 aísla cuatro canales en un chip, pero es
más caro y difícil de conseguir. \\
Acceso a GPIO & \id{pigpio} & \id{libgpiod} y WiringPi no generan PWM ni
pulsos de servo con temporización estable; \id{pigpio} lo hace por DMA, mide
el eco en microsegundos y da el bus I2C por el mismo demonio. \\
Servidor web & \id{libmicrohttpd} & nginx o lighttpd son un proceso aparte
con CGI que mantener; un servidor en Python suma unos 40\,MB al rootfs. \\
Decodificador MP3 & \id{mpg123} & GStreamer trae decenas de MB de plugins
para el mismo resultado. \\
Imagen base & \id{core-image-minimal} & \id{core-image-base} y
\id{full-cmdline} arrastran utilidades y servicios que el robot no usa. \\
Chasis & Circular, impreso en 3D & El rectangular aprovecha mejor el
espacio, pero se traba en las esquinas al girar; el circular rota sobre su
eje sin barrer área extra. La impresión 3D permite integrar los apoyos de
cada componente y el cierre a presión en la misma pieza. \\
Algoritmo de cobertura & Aleatorio con rebote & Espiral y zig-zag dependen
de una odometría precisa; el rebote tolera el error acumulado y saca partido
de las siete direcciones del radar. \\
\bottomrule
\end{longtable}

% ===========================================================================
\section{DI3 --- Diseño de la alternativa seleccionada}

\subsection{Arquitectura de hardware}

Dos fuentes independientes alimentan los dos dominios: un power bank USB, la
Raspberry Pi y todo lo que trabaja a 5\,V; dos baterías alcalinas de 9\,V en
paralelo, el puente H y los motores. Las cuatro señales que cruzan del
dominio lógico al de potencia ---las entradas del puente H--- lo hacen por
optoacopladores, y las dos tierras no se tocan en ningún punto.

\begin{figure}[h]
\centering
\resizebox{\linewidth}{!}{%
\begin{tikzpicture}
  \node[blkl] (pb)   at (6.5,1.7)   {Power bank USB\\5\,V};
  \node[blkl] (pi)   at (10.0,1.7)  {Raspberry Pi 4\\\texttt{robot-image}};
  \node[blkl] (per)  at (14.3,1.7)  {Servo $\cdot$ HC-SR04 $\cdot$ MPU-6050\\4 LEDs $\cdot$ PAM8403};

  \node[blkn] (opto) at (10.0,0)    {4 $\times$ PC817};

  \node[blkp] (bat)  at (6.5,-1.7)  {2 baterías de 9\,V\\en paralelo};
  \node[blkp] (l298) at (10.0,-1.7) {L298N\\(\texttt{ENA}/\texttt{ENB} con jumper)};
  \node[blkp] (mot)  at (14.3,-1.7) {2 motores DC};

  \draw[ln] (pb) -- (pi);
  \draw[ln] (pi) -- (per);
  \draw[ln,dashed] (pi) -- (opto);
  \draw[ln,dashed] (opto) -- node[right,font=\scriptsize]{\texttt{IN1}--\texttt{IN4}} (l298);
  \draw[ln] (bat) -- (l298);
  \draw[ln] (l298) -- (mot);

  \begin{scope}[on background layer]
    \node[draw=cLog,dashed,rounded corners,fit=(pb)(pi)(per),inner sep=7pt,
          label={[font=\scriptsize\bfseries,text=cLog]above:Dominio lógico --- GND\_LOG}] {};
    \node[draw=cPot,dashed,rounded corners,fit=(bat)(l298)(mot),inner sep=7pt,
          label={[font=\scriptsize\bfseries,text=cPot]below:Dominio de potencia --- GND\_POT}] {};
  \end{scope}
\end{tikzpicture}}
\caption{Arquitectura de hardware. Las líneas punteadas son señales que
cruzan la barrera óptica. Los esquemas eléctricos completos están en
\texttt{hardware-diagramas.pdf}.}
\end{figure}

\paragraph{Alimentación.} Un power bank USB alimenta la Raspberry Pi por
USB-C. Del pin de 5\,V de la Pi salen el servo, el HC-SR04, el MPU-6050 y el
amplificador: unos 1.6\,A típicos. El dominio de potencia son dos baterías
alcalinas de 9\,V en paralelo, conectadas directo a la entrada del L298N; el
regulador de 5\,V del propio módulo alimenta su lógica y los pull-up de los
optoacopladores. El L298N cae unos 2\,V, así que a los motores les llegan
cerca de 7\,V. Detalle en \id{docs/hardware-alimentacion.md}.

\paragraph{Aislamiento.} Un PC817 por entrada del puente H. Resistencia de
entrada de 390\,$\Omega$, que fija 5\,mA por canal: con cuatro canales son
20\,mA, y junto con los LEDs el conector entrega 37\,mA de los 50\,mA que
admite. El servo no cruza la barrera: pertenece al dominio lógico y su señal
sale directo del GPIO 25. El L298N lleva los jumpers \id{ENA} y \id{ENB} puestos y se controla
solo con \id{IN1}--\id{IN4}, lo que ahorra dos optoacopladores y 10\,mA.
Detalle en \id{docs/hardware-aislamiento.md}.

\paragraph{Sensado.} Un HC-SR04 sobre un servo de 180° en el borde frontal,
con el eje 10\,cm por delante del centro. El pin \id{ECHO} entrega 5\,V y
pasa por un divisor de 1\,k$\Omega$ y 2\,k$\Omega$ (3.33\,V) antes del GPIO.
El MPU-6050 va entre las dos llantas, en un módulo GY-521 alimentado de los
5\,V de la Raspberry Pi: el módulo trae su propio regulador de 3.3\,V.
Detalle en
\id{docs/hardware-sensores.md}.

\paragraph{Indicadores y audio.} Cuatro LEDs de colores distintos a 5\,mA,
con la resistencia calculada para cada color. El audio sale por PWM en el
GPIO 18 (overlay \id{audremap}), pasa por un filtro RC con corte en 19\,kHz y
entra al PAM8403, alimentado de los 5\,V de la Raspberry Pi para que el ruido de los motores
no llegue al parlante.

\paragraph{Modelo físico.} Carcasa circular de 215\,mm de diámetro y 45\,mm
de alto, impresa en 3D en dos piezas que cierran a presión con cuatro
pestañas, sin tornillos. El diámetro es el máximo que admite la cama de la
impresora. Dos ruedas impresas de 30\,mm entran a presión en el eje de los
motores, 12\,mm por delante del centro, y una bola de 16\,mm sirve de apoyo
atrás; el piso queda a 8\,mm del suelo. Al frente, una campana lleva el aire
desde una boca de 70\,$\times$\,12\,mm hasta el ventilador de succión. El
modelo es paramétrico (CadQuery) y está en \id{modelo-3d/}; el detalle, en
\id{docs/hardware-chasis.md}.

\subsection{Arquitectura de software}

\begin{figure}[h]
\centering
\resizebox{\linewidth}{!}{%
\begin{tikzpicture}[node distance=5mm]
  \tikzset{capa/.style={blk,minimum width=13.2cm},
           media/.style={blk,minimum width=6.4cm}}
  \node[capa,blkn] (web) {Navegador del celular o la PC: \texttt{login.html} y \texttt{dashboard.html}};
  \node[capa,blkl,below=of web] (srv) {\textbf{\texttt{robot-server}}: API REST $\cdot$ autenticación $\cdot$ hilo de navegación (10\,Hz) $\cdot$ mapa de 31 $\times$ 31};
  \node[capa,blkl,below=of srv] (lib) {\textbf{\texttt{librobot.so.1}}: motores $\cdot$ servo $\cdot$ radar (hilo) $\cdot$ MPU-6050 $\cdot$ odometría (hilo, 50\,Hz) $\cdot$ LEDs $\cdot$ audio (hilo)};
  \node[media,blkn,below=of lib.south west,anchor=north west] (pig) {\texttt{pigpiod}: GPIO, PWM y pulsos por DMA, I2C};
  \node[media,blkn,below=of lib.south east,anchor=north east] (snd) {\texttt{mpg123} y ALSA};
  \node[capa,blkn,below=24mm of lib] (ker) {Linux 6.6 y \texttt{systemd} --- imagen \texttt{robot-image} (Yocto \texttt{scarthgap})};
  \node[capa,blkp,below=of ker] (hw) {Raspberry Pi 4 $\cdot$ L298N $\cdot$ servo $\cdot$ HC-SR04 $\cdot$ MPU-6050 $\cdot$ LEDs $\cdot$ PAM8403};

  \draw[ln] (web) -- node[right,font=\scriptsize]{HTTP en el puerto 8080, JSON, sondeo cada 500\,ms} (srv);
  \draw[ln] (srv) -- node[right,font=\scriptsize]{única vía de acceso al hardware} (lib);
  \draw[ln] (lib.south -| pig) -- (pig);
  \draw[ln] (lib.south -| snd) -- (snd);
  \draw[ln] (pig) -- (pig |- ker.north);
  \draw[ln] (snd) -- (snd |- ker.north);
  \draw[ln] (ker) -- (hw);
\end{tikzpicture}}
\caption{Arquitectura de software por capas.}
\end{figure}

\paragraph{Sistema operativo.} La imagen \id{robot-image} parte de
\id{core-image-minimal} y agrega solo lo que el robot usa; cada paquete está
justificado en \id{docs/paquetes.md}. La capa propia \id{meta-robot} aporta
las recetas de \id{librobot}, \id{robot-server}, \id{pigpio}, la
configuración de ALSA y de WiFi, los ajustes de \id{config.txt} y la tabla
de particiones. La música va en una tercera partición, de modo que ninguna
supera los 200\,MB.

\paragraph{Biblioteca.} \id{librobot} es la única vía de acceso al hardware.
Una llamada, \id{robot_init()}, abre la sesión e inicia dos hilos propios: la
odometría a 50\,Hz y el barrido del radar. El audio corre en un tercer hilo.
La referencia completa está en \id{docs/api-librobot.md}.

\paragraph{Servidor.} \id{robot-server} sirve la interfaz, expone la API y
corre el hilo de navegación a 10\,Hz. No espera al radar: lee la última
lectura de cada ángulo cuando la necesita. Las contraseñas se guardan como
resumen SHA-256 y la sesión viaja en una cookie \id{HttpOnly} que caduca a
los 10 minutos de inactividad.

\paragraph{Arranque.} Dos unidades \id{systemd}, habilitadas desde las
recetas. \id{robot-server} declara \id{Requires=pigpiod.service} y
\id{Restart=on-failure} con un límite de cinco reintentos por minuto.

\subsection{Navegación}

El robot avanza hasta que detecta un obstáculo por cualquiera de dos vías:
el tiempo antes de chocar baja de 1.2\,s, o alguna lectura del cono frontal
(60°, 90°, 120°) baja de 20\,cm. Entonces se detiene, suena el aviso y
enciende el LED rojo. En modo autónomo sigue la evasión:

\begin{enumerate}
  \item retrocede medio segundo;
  \item espera un barrido completo del radar, ya quieto;
  \item elige el rumbo con más espacio entre las seis direcciones que no son
        el frente; las que quedan a menos de 25\,cm de la mejor compiten al
        azar, que es la parte aleatoria del rebote;
  \item gira en lazo cerrado sobre el rumbo del giroscopio hasta cubrir el
        ángulo elegido, no durante un tiempo fijo.
\end{enumerate}

En modo manual la misma detección actúa como freno de seguridad.

\subsection{Elementos propios del diseño}
\label{sec:creativo}

\begin{itemize}
  \item \textbf{Tiempo antes de chocar.} Cada lectura frontal se congela con
        el avance acumulado en ese instante. Entre dos lecturas, la distancia
        se proyecta con lo que el robot avanzó y se divide entre la velocidad
        actual: $t = (d - \Delta\text{avance}) / v$. La cuenta regresiva
        sigue bajando aunque el sensor esté mirando a un lado, y compensa la
        baja frecuencia de la lectura frontal del radar.
  \item \textbf{Fusión de la velocidad.} Un filtro complementario deja pasar
        la dinámica rápida del acelerómetro y toma del modelo de los motores
        la tendencia lenta ($\tau = 1$\,s); con los motores detenidos la
        velocidad se fuerza a cero. Así el sesgo del acelerómetro no se
        acumula.
  \item \textbf{La inversión se compensa en un solo punto.} Los cuatro
        canales del puente H van en emisor común, que invierte la señal. La
        inversión se compensa en un único lugar de \id{lib_motors.c}, y el
        simulador invierte igual que la placa: si alguien quita la
        compensación, la prueba falla.
  \item \textbf{El reposo es seguro.} Con los GPIO en bajo, las cuatro
        entradas del L298N quedan en alto por sus resistencias: con el puente
        habilitado eso es freno, no movimiento.
  \item \textbf{Desarrollo sin hardware.} Un simulador reemplaza a
        \id{pigpiod} por un robot virtual en una sala de 4 $\times$ 4\,m, sin
        tocar una línea de la biblioteca. Una máquina \id{qemuarm64-robot}
        con el mismo \emph{tune} Cortex-A72 arranca la imagen completa con
        los mismos binarios de espacio de usuario que corren en la Pi.
  \item \textbf{Imagen reproducible sin secretos.} Si falta el archivo de
        credenciales de WiFi, la receta usa la plantilla y avisa: un clon
        limpio produce la imagen sin pasos manuales, como exige R18.
\end{itemize}

\subsection{Cómo responde el diseño a seguridad, costo e impacto}

\begin{center}
\begin{tabularx}{\linewidth}{L{2.6cm}Y}
\toprule
\textbf{Aspecto} & \textbf{Respuesta del diseño} \\
\midrule
Seguridad & Power bank con la protección de su celda de fábrica, dos fuentes
independientes, aislamiento óptico con tierras separadas, divisor en
\id{ECHO}, freno en reposo y freno
automático en modo manual, \id{pigpiod} con \id{-l} (solo interfaz local),
inicio de sesión obligatorio. \\
Costo & Se reutilizó el sensor, el MPU-6050 y el L298N del grupo. El radar
evitó comprar dos sensores; el MPU-6050 evitó los encoders; el PAM8403
reemplazó ocho componentes discretos. \\
Ambiental & Amplificador clase D; módulos con conectores desconectables y
reutilizables; power bank recargable. Las baterías de 9\,V son alcalinas
desechables: es el punto débil del diseño, y al agotarse se llevan a un punto
de recolección. \\
\bottomrule
\end{tabularx}
\end{center}

% ===========================================================================
\section{DI4 --- Validación del diseño final}

\subsection{Estrategia}

La validación se hizo en tres niveles, de menor a mayor costo de cada
iteración:

\begin{enumerate}
  \item \textbf{Simulador en el host.} \id{sim/prueba_librobot} ejercita
        cada módulo de la biblioteca contra el robot virtual y compara con la
        verdad del mundo simulado: 47 comprobaciones.
  \item \textbf{Emulación ARM.} El mismo programa, compilado con el
        Toolchain-SDK, corre bajo \id{qemu-aarch64}; y la imagen completa
        arranca en la máquina \id{qemuarm64-robot}.
  \item \textbf{Target.} La imagen en la Raspberry Pi 4 con el robot armado,
        siguiendo los procedimientos de verificación de \id{docs/}.
\end{enumerate}

\subsection{Matriz de cumplimiento}
\label{sec:matriz}

\begin{longtable}{L{0.8cm}L{6.3cm}L{1.9cm}L{5.4cm}}
\toprule
\textbf{Id.} & \textbf{Cómo se validó} & \textbf{Resultado} & \textbf{Evidencia} \\
\midrule
\endhead
R1 & Dos minutos en modo autónomo sobre el simulador: 18 evasiones y ningún
choque. Prueba de campo en un área delimitada. & Cumple &
\ruta{docs/navegacion-radar.md} \\
R2 & Barrido completo contra el mundo simulado: los siete ángulos a menos de
2\,cm de la distancia real, a 5 lecturas por segundo. Un HC-SR04 sobre el
servo y un MPU-6050. & Cumple, con desviación acordada &
\ruta{sim/prueba_librobot.c} \\
R3 & Avance, retroceso, giros y detención verificados en el simulador;
sentido de giro confirmado con el robot elevado. Velocidad fija, sin PWM. &
Cumple, con desviación acordada &
\ruta{docs/evidencias/ejecucion-cruzada-qemu.md} \\
R4 & Cada LED cambia de estado al ordenarlo y sigue al modo activo. & Cumple
& \ruta{docs/evidencias/servidor-web.md} \\
R5 & Reproducción en un hilo propio mientras el hilo de navegación corre. &
Cumple & \ruta{lib/lib_audio.c} \\
R6 & Listar, reproducir, pausar, detener y volumen por HTTP. & Cumple &
\ruta{sim/prueba_api.sh} \\
R7 & Tono de prueba y sonido de evento por el parlante del robot. & Cumple &
\ruta{docs/hardware-sensores.md} \\
R8 & Los cuatro eventos disparan su sonido; el aviso pausa la música y la
reanuda. & Cumple & \ruta{docs/api-librobot.md} \\
R9 & Cambio de modo y movimiento manual por HTTP; los controles manuales se
bloquean en autónomo. & Cumple & \ruta{docs/evidencias/servidor-web.md} \\
R10 & \id{/api/status} entrega modo, sensores, LEDs, audio y mapa en una sola
consulta, cada 500\,ms. & Cumple & \ruta{docs/evidencias/servidor-web.md} \\
R11 & La grilla crece en tiempo real: de 79 a 85 celdas visitadas en 6\,s. &
Cumple & \ruta{docs/evidencias/servidor-web.md} \\
R12 & Credenciales inválidas y consultas sin sesión devuelven 401. & Cumple
& \ruta{docs/evidencias/servidor-web.md} \\
R13 & Tras un \id{kill -9}, el servicio vuelve con otro PID y
\id{NRestarts=1}. & Cumple & \ruta{docs/evidencias/systemd-reinicio.md} \\
R14 & El servidor declara \id{NEEDED librobot.so.1} y no toca GPIO. & Cumple
& \ruta{docs/evidencias/binarios-target.md} \\
R15 & Los logs muestran \id{aarch64-poky-linux-gcc}; los binarios son ELF
ARM aarch64 y no ejecutan en el host. & Cumple & \ruta{docs/evidencias/} \\
R16 & Imagen sobre \id{core-image-minimal}; cada paquete agregado, listado y
justificado. & Cumple & \ruta{docs/paquetes.md} \\
R17 & Ambas recetas heredan \id{cmake}; la biblioteca se empaqueta en
\id{librobot} y \id{librobot-dev}. & Cumple & \ruta{meta-robot/} \\
R18 & \id{bitbake robot-image} produce la imagen desde un clon limpio. &
Cumple & \ruta{docs/yocto-setup.md} \\
R19 & Ver la sección~\ref{sec:metricas}. & Ver tabla & \ruta{docs/metricas.md} \\
RO1 & Tres minutos en autónomo sobre el simulador, con una grada que el
HC-SR04 no ve: una detección con evasión y ninguna caída. Falta montar los
sensores en el robot. & Cumple en simulador & \ruta{docs/opcionales.md} \\
RO2 & Con una meta de 12\,s el robot se detuvo a los 12.5\,s, sonó el aviso
y el panel marcó el ciclo completo. & Cumple & \ruta{docs/opcionales.md} \\
RO3 & La playlist se guardó, sobrevivió a un reinicio del servidor y se
reprodujo en orden y en bucle. & Cumple & \ruta{docs/opcionales.md} \\
\bottomrule
\end{longtable}

\paragraph{Desviaciones acordadas con el profesor.} En dos requerimientos el
diseño se aparta de la letra del enunciado. Ambos casos se consultaron con el
profesor.

\begin{itemize}
  \item \textbf{R3, velocidad sin PWM.} El robot avanza, retrocede, gira
        hacia los dos lados y se detiene, que es el control diferencial que
        se pide. Lo que no usa es PWM: los motores van a velocidad fija. Son
        motorreductores lentos y de alto torque (30\,rpm a 6\,V y 60\,rpm
        a 12\,V; 110 y 200\,oz-in a rotor bloqueado) que trabajan a unos
        9\,V, lo que da la batería. Con ruedas de 30\,mm el robot avanza a
        unos 5\,cm/s;
        con la tensión recortada por la PWM el robot no se mueve (hallazgo 3
        de la sección~\ref{sec:hallazgos}). Se acordó con el profesor que la
        PWM no era necesaria.
  \item \textbf{R2, sensores.} El robot lleva un solo sensor de proximidad,
        un HC-SR04 que sobre el servo cubre las detecciones frontal y
        lateral, y un MPU-6050 que aporta el giroscopio. El profesor lo
        consideró suficiente: lo que busca es que el robot tenga dos
        sensores.
\end{itemize}

\subsection{Validación de la seguridad}

Antes de conectar la Raspberry Pi se ejecutaron, en orden, los procedimientos
de verificación de \id{docs/hardware-aislamiento.md} y
\id{docs/hardware-alimentacion.md}. Todas las verificaciones pasaron:

\begin{center}
\begin{tabularx}{\linewidth}{Y L{4.6cm}C{1.8cm}}
\toprule
\textbf{Verificación} & \textbf{Criterio} & \textbf{Resultado} \\
\midrule
Continuidad entre \id{GND_LOG} y \id{GND_POT}, todo desenergizado &
Circuito abierto ($>$ 1\,M$\Omega$) & Pasó \\
Continuidad entre el pin de 5\,V de la Raspberry Pi y \id{VS} del L298N &
Circuito abierto & Pasó \\
Salida de 5\,V del L298N, que alimenta \id{VSS} y los pull-up de los
optoacopladores & 5 $\pm$ 0.25\,V & Pasó \\
Entradas del L298N con los optoacopladores en reposo &
$\approx$ 5\,V: motores frenados & Pasó \\
Salida del divisor de \id{ECHO} al disparar el sensor & 3.3\,V como máximo &
Pasó \\
Raspberry Pi navegando con audio, alimentada del power bank & Sin reinicios
ni subtensión & Pasó \\
\bottomrule
\end{tabularx}
\end{center}

La separación entre los dos dominios no depende de un regulador: cada uno
tiene su propia fuente, y las únicas señales que cruzan lo hacen por los
optoacopladores.

\subsection{Validación de la eficiencia}
\label{sec:metricas}

\begin{center}
\begin{tabularx}{\linewidth}{L{2.9cm}C{1.9cm}C{3.1cm}Y}
\toprule
\textbf{Métrica} & \textbf{Referencia} & \textbf{Medido} & \textbf{Método} \\
\midrule
Rootfs & $\leq$ 200\,MB & 129\,MB & \id{du} sobre el rootfs de la imagen
construida. La partición raíz es de tamaño fijo, 180\,MiB. \\
Tiempo de arranque & $\leq$ 15\,s & 19.2\,s & Instante en que
\id{robot-server} escucha en el puerto 8080, en la Raspberry Pi 4 con WiFi. \\
RAM en operación & --- & 97\,MB de 1845\,MB & \id{/proc/meminfo};
\id{robot-server} ocupa 5.2\,MB (\id{VmRSS}). \\
CPU en operación & --- & 3.6\,\% de 4 núcleos & \id{/proc/stat} durante 60\,s;
\id{robot-server} usa el 4.5\,\% de un núcleo. \\
\bottomrule
\end{tabularx}
\end{center}

Medido sobre la imagen final con el robot armado, en modo autónomo, con
música y el panel consultando el estado cada 500\,ms. El rootfs queda en el
65\,\% del presupuesto, y la RAM y la CPU dejan margen de sobra. El arranque
excede la referencia por 4.2\,s: \id{robot-server} espera a que la red esté
operativa (\id{network-online.target}), y la búsqueda del punto de acceso
WiFi se lleva casi 7\,s; desde que hay red, el servidor escucha en 1.5\,s. Se considera una desviación justificada, porque sin red
el panel de control no es alcanzable y el servicio no estaría operativo en
el sentido del enunciado. El método completo está en \id{docs/metricas.md}.

\subsection{Validación del costo y del impacto}
\label{sec:costo}

\begin{itemize}
  \item \textbf{Costo.} El grupo gastó 134 USD, por encima del límite
        superior de la estimación (99 USD). La diferencia tiene dos causas.
        La primera es que 44 USD no terminaron en el robot: 24 de los motores
        y el ventilador del primer diseño, que se descartaron al rehacerlo, y
        20 de la aspiradora que se desarmó para hacerle ingeniería inversa.
        La segunda es que la impresión 3D costó 50 USD, el doble del máximo
        previsto para el bloque de chasis y acabado. Lo que quedó en el robot
        suma 90 USD, dentro del intervalo estimado. La
        lección es cerrar el diseño mecánico antes de comprar los motores y
        cotizar la impresión antes de fijar el chasis.
  \item \textbf{Impacto ambiental.} Todos los módulos quedaron con conectores
        desconectables; la Raspberry Pi se devuelve sin soldaduras ni
        adhesivos; el power bank es recargable. Las dos baterías de 9\,V
        son alcalinas desechables, el mayor impacto del diseño final: se
        entregan a un punto de recolección al agotarse.
\end{itemize}

\subsection{Hallazgos de la validación y acciones correctivas}
\label{sec:hallazgos}

Validar no fue solo confirmar: varias pruebas cambiaron el diseño.

\begin{longtable}{L{0.5cm}L{4.4cm}L{4.9cm}L{4.7cm}}
\toprule
& \textbf{Hallazgo} & \textbf{Causa} & \textbf{Acción} \\
\midrule
\endhead
1 & El límite de reintentos de \id{systemd} no existía. &
\id{StartLimitIntervalSec} estaba en \id{[Service]}; desde systemd 229 va en
\id{[Unit]} y en otro lugar se ignora en silencio. & Se movió a \id{[Unit]}.
Lo detectó \id{systemd-analyze verify}. \\
2 & Con los optoacopladores, los motores girarían al revés. & El PC817 en
emisor común invierte la señal. & Compensación en un único punto de
\id{lib_motors.c}; el simulador invierte igual que la placa, así que quitarla
hace fallar la prueba. \\
3 & Con PWM de 1\,kHz los motores no se movieron. & El PC817 con pull-up de
4.7\,k$\Omega$ tarda decenas de microsegundos en apagarse; sumado a los 2\,V
que cae el L298N, a ciclos medios el motor no alcanza su tensión de arranque.
& Velocidad fija, sin PWM. Los motores dan 60\,rpm a 12\,V y trabajan a unos
9\,V: con la tensión recortada no mueven el robot. Se consultó con el profesor
y se acordó la desviación. \\
4 & El servidor arrancaba a los 130\,s. & \id{eth0} sin cable y dos clientes
DHCP sobre \id{wlan0} agotaban la espera de red. & Ethernet marcada como no
requerida y un solo cliente DHCP: 17\,s. \\
5 & El vaivén del servo sacudía el sensor y el chasis. & El servo iba a su
velocidad máxima entre paradas. & Rampa a un tercio de la velocidad, con un
pulso intermedio cada 20\,ms. \\
6 & El \emph{build} colgaba el host al 67\,\%. & Tres compilaciones pesadas
a la vez agotaron 7\,GB de RAM y el swap. & Dos hilos y regulación por
presión de recursos (\id{BB_PRESSURE_MAX_MEMORY}). \\
7 & Una Raspberry Pi dejó de funcionar durante el desarrollo. & No se
determinó; se presume la antigüedad de la tarjeta. & Se reportó al profesor,
quien la reemplazó, y el proyecto continuó con la nueva. \\
\bottomrule
\end{longtable}

\subsection{Limitaciones conocidas}

\begin{itemize}
  \item Los motores van a velocidad fija, sin PWM: el robot gira sobre su
        eje, no en curvas de radio variable. Es una desviación acordada con
        el profesor.
  \item El radar usa un solo sensor de proximidad para cubrir las detecciones
        frontal y lateral; el otro sensor del robot es el MPU-6050. También
        es una desviación acordada. Los GPIO 22 y 10 quedaron libres para un
        segundo HC-SR04 fijo al frente.
  \item Sin encoders, la distancia recorrida depende de la calibración del
        modelo de los motores; el mapa sirve para la sesión, no como posición
        absoluta.
  \item Una lectura sin eco no significa camino libre: una pared oblicua
        desvía el pulso. El mapa no usa esas lecturas para despejar celdas.
  \item Las baterías de 9\,V tienen poca capacidad y su tensión cae bajo la
        corriente de los motores: la autonomía de la tracción es corta y
        conviene tener repuestos a mano.
  \item Los sensores de desnivel se probaron solo en el simulador: falta
        montarlos y ajustar su umbral sobre el piso de la demostración.
  \item La meta del ciclo de limpieza vive en memoria: vuelve a ``sin
        límite'' al reiniciar el robot.
\end{itemize}

% ===========================================================================
\section{Conclusiones}

El diseño cumple los requerimientos obligatorios, con dos desviaciones
acordadas con el profesor (velocidad fija en vez de PWM, y un sensor de
proximidad sobre un servo junto con un giroscopio), con un rootfs de 129\,MB
y un modelo físico construido con el inventario del grupo y una compra
acotada.
Las decisiones que más pesaron ---radar sobre servo, dos fuentes independientes,
MPU-6050 fusionado con el modelo de los motores--- se tomaron comparando
alternativas con criterios técnicos, económicos, ambientales y sociales, y
cada una dejó una debilidad conocida que el propio diseño atiende.

La validación en tres niveles permitió avanzar el software antes de tener el
hardware, pero también mostró su límite: el problema de la PWM a través del
optoacoplador solo apareció en la placa real. El diseño de un sistema
embebido se cierra en el hardware.

\section{Referencias}

\begin{itemize}
  \item J. González Gómez, \emph{Especificación Proyecto I}, CE-1113 Sistemas
        Empotrados, Tecnológico de Costa Rica, 2026.
  \item Yocto Project, \emph{Reference Manual} y \emph{Development Tasks
        Manual}, versión 5.0 (\id{scarthgap}).
  \item Raspberry Pi Ltd., documentación de la Raspberry Pi 4 Model B: GPIO,
        \id{config.txt} y \emph{device tree overlays}.
  \item \id{pigpio}, documentación de la interfaz \id{pigpiod_if2}.
  \item Hojas de datos: Sharp PC817, STMicroelectronics L298N, InvenSense
        MPU-6050, Diodes Inc. PAM8403, HC-SR04.
  \item Repositorio del proyecto:
        \url{https://github.com/Randall-BL/EmpotradosProyecto1}.
\end{itemize}

\end{document}

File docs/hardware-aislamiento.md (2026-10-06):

# Etapa de potencia con aislamiento galvánico

> **Lectura obligatoria antes de energizar nada.** Conectar un GPIO directamente a la
> circuitería de motores puede destruir la Raspberry Pi de forma irreversible. El equipo
> es prestado por el curso y el daño es responsabilidad del grupo.

---

## Por qué hace falta

Un motor DC es una carga inductiva. Al conmutar o al frenar genera picos de tensión
inversa de decenas de voltios sobre la línea de alimentación y sobre la referencia de
tierra. Si la tierra de los motores y la tierra de la Raspberry Pi son el mismo cobre,
ese pico aparece en el conector de 40 pines.

Tres cosas lo hacen peor en este robot:

1. **Corriente de arranque.** Un motor DC pequeño arrancando consume entre 5 y 8 veces
   su corriente nominal durante decenas de milisegundos.
2. **Arranques y frenados.** Cada vez que el robot arranca, frena o evade un obstáculo
   la corriente del motor se conmuta de golpe. Cada flanco es un transitorio.
3. **Inversión de sentido.** Pasar de avance a retroceso invierte la corriente en un
   inductor cargado: es el peor caso.

El GPIO de la Raspberry Pi **no tiene diodos de protección hacia 3.3 V** y tolera
3.3 V como máximo absoluto. No hay margen.

---

## Solución adoptada: PC817 en las cuatro señales de los motores

El L298N se usa con los **jumpers `ENA` y `ENB` puestos**: el puente queda siempre
habilitado y esos pines no salen a la Raspberry Pi. Los motores se controlan con
**niveles fijos sobre las entradas de sentido** `IN1`–`IN4` (ver
[Velocidad fija](#velocidad-fija)), así que hacia el dominio de potencia cruzan cuatro
señales, y las cuatro lo hacen por un optoacoplador. El **servo del radar** no cruza
la barrera: se alimenta de los 5 V de la Raspberry Pi y su señal sale directo del GPIO
(ver [más abajo](#el-servo-va-en-el-dominio-lógico)).

```
     DOMINIO LÓGICO (3.3 V)          │        DOMINIO DE POTENCIA (9 V)
     GND_LOG                         │        GND_POT
                                     │
  GPIO ──[R 390Ω]──┐             ┌───┼──── +5V_POT
                   │             │   │        │
                 ┌─┴─┐           │   │      [R 4.7kΩ]
                 │ ▼ │ LED       │   │        │
   PC817         │   │           │   │        ├──────► entrada del L298N
                 │ ⊂ │ fototrans.│   │        │
                 └─┬─┘           └───┼────────┘ colector
                   │      emisor ────┼──── GND_POT
                GND_LOG              │
                                     │
                        ↑ AISLAMIENTO GALVÁNICO
                          sin cobre en común
```

Se repite cuatro veces, una por entrada: `IN1`, `IN2`, `IN3`, `IN4`.

### Cómo mueve los motores el L298N sin `ENA`/`ENB`

Con el puente siempre habilitado, cada par de entradas decide el estado del motor:

| `IN1` | `IN2` | Motor A |
|---|---|---|
| Alto | Bajo | Avanza |
| Bajo | Alto | Retrocede |
| Bajo | Bajo | **Frenado** (las dos salidas a tierra: el motor queda en cortocircuito) |
| Alto | Alto | **Frenado** (las dos salidas al positivo) |

Para avanzar, `IN1` en alto e `IN2` en bajo; para retroceder, al revés. Detenerse es
dejar las dos en bajo: **frena en seco**, no queda girando libre. Igual para `IN3`/`IN4`
y el motor B. Para girar, un motor hacia adelante y el otro hacia atrás: el robot rota
sobre su eje.

Los pines `GPIO 12` y `13`, que antes llevaban `ENA`/`ENB`, quedan libres.

### Velocidad fija

Los motores trabajan **sin PWM**: la entrada activa lleva un nivel fijo y cualquier
velocidad distinta de cero es la máxima (`MOTOR_VELOCIDAD_VARIABLE` en 0, en
`lib/lib_motors.h`). El robot avanza, retrocede, gira sobre su eje hacia los dos lados y
frena, que es el control diferencial que pide el enunciado.

> **Desviación acordada con el profesor.** El enunciado pide que la velocidad de cada
> motor se controle por PWM. Se le consultó al profesor y se acordó que en este robot la
> PWM no es necesaria, porque con ella el robot no se mueve.

La razón está en los motores. Son motorreductores lentos y de alto torque (30 rpm a 6 V
y 60 rpm a 12 V; 110 y 200 oz-in a rotor bloqueado) y trabajan a unos 9 V, que es lo que
da la batería. El L298N cae unos 2 V, así que a fondo les llegan unos 7 V: con ruedas de
30 mm, el robot avanza a unos 5 cm/s. Recortar esa tensión con PWM los deja por debajo
de lo que necesitan para mover el robot.

Se comprobó en la placa: con PWM de 1 kHz sobre la entrada activa **los motores no se
movieron**. A la caída del L298N se suma que el PC817 con 4.7 kΩ de pull-up tarda decenas
de microsegundos en apagarse, y en cada ciclo se come parte del tiempo en que la entrada
debía estar en alto.

El modo con PWM sigue en la biblioteca (`MOTOR_VELOCIDAD_VARIABLE` en 1) y está probado
en el simulador, pero el robot no lo usa.

### Cálculo de la resistencia de entrada

El LED interno del PC817 tiene `Vf ≈ 1.2 V`:

```
R = (3.3 V − 1.2 V) / If
```

| `If` | R calculada | R comercial | Corriente total (×4) |
|---|---|---|---|
| 5 mA | 420 Ω | **390 Ω** | 20 mA |
| 8 mA | 262 Ω | 270 Ω | 32 mA |
| 10 mA | 210 Ω | 220 Ω | 40 mA ⚠️ |

**Se usa 390 Ω.** El límite de corriente sumada de todos los GPIO de la Raspberry Pi es
de 50 mA, y a eso hay que restarle todavía los LEDs indicadores.
Con 5 mA por canal los cuatro optos suman 20 mA y queda holgura para los LEDs, de los que
nunca hay más de tres encendidos (15 mA). La cuenta
completa está en [`hardware-pinout.md`](hardware-pinout.md).

El PC817 con `CTR` mínimo de 50 % da 2.5 mA de colector con `If = 5 mA`. Contra la
resistencia de 4.7 kΩ a 5 V eso satura el transistor de sobra: hacen falta apenas
1.1 mA para llevar la salida a nivel bajo.

### Resistencia de salida

`4.7 kΩ` de colector a `+5V_POT`. Con `Cpar ≈ 10 pF` de la entrada del L298N la
constante de tiempo es de unos 50 ns, despreciable. Lo que manda es el apagado del
propio PC817: con la carga de 4.7 kΩ y el transistor saturado tarda decenas de
microsegundos. Con niveles fijos, que es como trabaja el robot, no importa; con PWM de
1 kHz fue parte de por qué los motores no se movieron (ver [arriba](#velocidad-fija)).

Bajarla a 1 kΩ acelera el apagado pero consume 5 mA por canal del riel de potencia.

---

## ⚠️ El optoacoplador invierte la señal

En configuración de emisor común —la del diagrama— el fototransistor **conduce** cuando
el LED está encendido, y al conducir lleva la salida a **nivel bajo**:

| GPIO | LED del opto | Fototransistor | Entrada del L298N |
|---|---|---|---|
| Alto (3.3 V) | Encendido | Conduce | **Bajo** |
| Bajo (0 V) | Apagado | Corte | **Alto** (por el pull-up) |

Sin compensarlo, la entrada que debía quedar en bajo queda en alto y la que debía
quedar en alto, en bajo: cada motor **gira al revés**: `motores_avanzar()` haría retroceder el robot y el giro a
la derecha sería a la izquierda.

### Cómo se compensa

**En software, en `lib/lib_motors.c`**, el único punto donde la biblioteca toca los
motores:

```c
#define OPTO_INVERTIDO 1

static void entrada_l298n(unsigned gpio, int duty) {
#if MOTOR_VELOCIDAD_VARIABLE
  #if OPTO_INVERTIDO
    duty = MOTOR_PWM_MAX - duty;          /* PWM: se complementa el ciclo */
  #endif
    set_PWM_dutycycle(g_pi, gpio, (unsigned)duty);
#else
    int nivel = duty > 0;
  #if OPTO_INVERTIDO
    nivel = !nivel;                       /* nivel fijo: se invierte */
  #endif
    gpio_write(g_pi, gpio, (unsigned)nivel);
#endif
}
```

Todas las escrituras a `IN1`–`IN4` pasan por esa función. Para una prueba de banco con el
L298N conectado **sin** optoacopladores, `OPTO_INVERTIDO` va en 0; con la placa de
optos, siempre en 1. El simulador (`sim/pigpio_sim.c`) invierte la señal como la placa
real, así que si alguien quita la compensación la prueba de avance falla.

La alternativa —una segunda inversión en hardware, con un 74HC04 o un transistor por
canal— son cuatro componentes más y más puntos de falla para resolver lo que resuelve una
resta.

### El reposo es seguro

Durante el arranque, antes de que `pigpiod` configure los pines, o si el servidor se
detiene, los GPIO quedan en bajo: los LED de los optos apagados y las cuatro entradas del
L298N en alto por los pull-up. Con el puente habilitado eso es **freno**, no movimiento.

---

## El servo va en el dominio lógico

El servo del radar se alimenta del **pin de 5 V de la Raspberry Pi** y su señal sale
**directo del GPIO 25**, sin optoacoplador. Un servo de este tamaño acepta el pulso de
3.3 V como nivel alto, y al compartir fuente y tierra con la Pi no hay barrera que
cruzar.

Los pulsos los genera `pigpiod` por DMA (`set_servo_pulsewidth`). En reposo el GPIO
queda en bajo y el servo no recibe pulsos: se queda donde estaba.

El costo de esta decisión es que los picos de corriente del servo entran al riel de 5 V
de la Pi; cómo se mantienen controlados está en
[`hardware-alimentacion.md`](hardware-alimentacion.md).

---

## Separación de tierras

Es la mitad del asunto y la que más se equivoca.

```
     ┌──────────────── DOMINIO LÓGICO ────────────────┐
     │  Raspberry Pi 4                                │
     │  HC-SR04 del radar                             │
     │  MPU-6050                                      │
     │  LEDs indicadores                              │
     │  Amplificador de audio PAM8403 + parlante      │
     │  Servo del radar                               │
     │  Lado LED de los 4 optoacopladores             │
     │                                                │
     │  Todos referidos a GND_LOG                     │
     └────────────────────────────────────────────────┘
                          ╳  SIN CONEXIÓN
     ┌─────────────── DOMINIO DE POTENCIA ────────────┐
     │  Driver L298N (VS, VSS y jumpers ENA/ENB)      │
     │  2 motores DC                                  │
     │  2 baterías de 9 V en paralelo                 │
     │  Lado fototransistor de los 4 optoacopladores  │
     │                                                │
     │  Todos referidos a GND_POT                     │
     └────────────────────────────────────────────────┘
```

**`GND_LOG` y `GND_POT` no se tocan en ningún punto.** Ni con un cable, ni por el chasis,
ni por la carcasa de un conector metálico. Si se unen, el aislamiento deja de existir y
los optoacopladores no sirven de nada.

### El error más común

El L298N tiene un pin `+5V` (`VSS`) para su propia lógica interna. **Ese pin NO se
conecta a los 5 V de la Raspberry Pi.** Si se conecta, la tierra de referencia de la
lógica del L298N pasa a ser la de la Pi y el aislamiento queda anulado, aunque los cuatro
optoacopladores estén perfectamente montados.

`VSS` se alimenta desde el regulador interno del propio módulo L298N, con el jumper de
5 V puesto: es válido mientras `VS ≤ 12 V`, y las baterías dan 9 V. De esa misma salida
(`+5V_POT`) cuelgan los pull-up de los optoacopladores.

---

## Alternativa: driver con aislamiento integrado

El DRV8871 acepta entrada de 3.3 V directa, pero **no aísla galvánicamente**: comparte
tierra. Sirve para simplificar el nivel lógico, no para reemplazar los optoacopladores.

Si se prefiere un componente en vez de cuatro, un **ADuM1401** (aislador digital de
cuatro canales) cubre las cuatro entradas del L298N con aislamiento real, y es lo
bastante rápido para la PWM. Es más caro y más difícil de conseguir localmente que
cuatro PC817.

**Se mantiene la solución con PC817.**

> El servo y el HC-SR04 que lleva encima pertenecen los dos al dominio lógico: su
> alimentación y sus señales llegan desde la Raspberry Pi. Ninguno de sus cables debe
> tocar el lado de potencia.

---

## Lista de materiales

| Cantidad | Componente | Notas |
|---|---|---|
| 4 | Optoacoplador PC817 (o 4N25) | Uno por entrada: `IN1`–`IN4` |
| 4 | Resistencia 390 Ω, 1/4 W | Limitación del LED, canales del L298N |
| 4 | Resistencia 4.7 kΩ, 1/4 W | Pull-up de colector hacia `+5V_POT` |
| 1 | Driver L298N (módulo) | Doble puente H, **con los jumpers `ENA` y `ENB` puestos** |
| 4 | Diodo 1N5822 (Schottky) | Volante, si el módulo no los trae |
| 1 | Capacitor 100 µF electrolítico | Desacople en `VS` del L298N |
| 2 | Capacitor 100 nF cerámico | Desacople en `VSS` y en el L298N |

> Muchos módulos L298N ya traen los diodos volantes. Verificar en la placa antes de
> agregarlos.

---

## Procedimiento de verificación — **antes de conectar la Raspberry Pi**

Se hace en este orden. No saltarse pasos.

### Paso 1 — Aislamiento, con todo desenergizado

Multímetro en continuidad:

| Entre | Debe medir |
|---|---|
| `GND_LOG` y `GND_POT` | **Circuito abierto** (sin pitido, > 1 MΩ) |
| `+3.3V` y `GND_LOG` | Sin corto |
| `+5V_POT` y `GND_POT` | Sin corto |
| Ánodo del LED de cada opto y `GND_POT` | **Circuito abierto** |

Si hay continuidad entre las dos tierras, **parar aquí** y encontrar el puente antes de
seguir.

### Paso 2 — Riel de potencia solo

Conectar únicamente las baterías de 9 V, sin la Raspberry Pi encendida.

| Punto | Esperado |
|---|---|
| `VS` del L298N | Alrededor de 9 V con baterías nuevas |
| `VSS` del L298N | 5 V ± 0.25 V |
| `ENA` y `ENB` del L298N | ~5 V: los jumpers están puestos |
| Entradas `IN1`–`IN4` (con optos en reposo) | ~5 V, por el pull-up — los motores quedan frenados |

### Paso 3 — Optoacopladores, con fuente de banco

Sin la Raspberry Pi todavía. Con una fuente de 3.3 V, inyectar en el ánodo de cada
opto a través de su resistencia de 390 Ω:

| Entrada del opto | Salida esperada en el L298N |
|---|---|
| 3.3 V | ~0.2 V (nivel bajo) |
| 0 V | ~5 V (nivel alto) |

Esto confirma el aislamiento y **confirma también la inversión** descrita arriba.

### Paso 4 — Dominio lógico solo

Conectar el power bank a la Raspberry Pi por USB-C, con las baterías de 9 V
desconectadas. La Pi debe arrancar y el servo, el sensor y el MPU-6050 deben responder
(ver [`hardware-sensores.md`](hardware-sensores.md)).

### Paso 5 — Conectar la Raspberry Pi

Solo si los cuatro pasos anteriores pasaron. Primero con los motores **desconectados
del L298N**, verificando por consola serie que arranca y que los GPIO responden. Los
motores se conectan de últimos.

La primera vez que se conectan, hacerlo **con el robot elevado** (llantas sin tocar el
piso), en modo manual, y avanzar desde el panel web: las dos llantas
tienen que girar hacia adelante. Si giran al revés, la compensación de la inversión no
coincide con la placa: revisar `OPTO_INVERTIDO` en `lib/lib_motors.c` y el Paso 3.

---

## Estado

- [x] Solución de aislamiento definida: 4 × PC817, uno por entrada del L298N
- [x] L298N siempre habilitado (jumpers `ENA`/`ENB`), control por `IN1`–`IN4`
- [x] Velocidad fija, con niveles fijos en `IN1`–`IN4` y sin PWM: desviación acordada con el profesor
- [x] Servo en el dominio lógico: 5 V de la Raspberry Pi y señal directa del GPIO 25
- [x] Resistencias calculadas contra el presupuesto de corriente del GPIO
- [x] Separación de tierras especificada, con el error común documentado
- [x] Inversión del optoacoplador identificada y compensada en `lib_motors.c` (`OPTO_INVERTIDO`)
- [x] Procedimiento de verificación con multímetro, en cinco pasos
- [x] Circuito armado
- [x] Verificación ejecutada: todos los pasos pasaron
- [ ] Compensación de la inversión verificada con la placa real (Paso 3 y primer avance con el robot elevado)

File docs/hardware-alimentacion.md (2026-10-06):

# Sistema de alimentación

Dos fuentes independientes, una por dominio: un **power bank USB** para la Raspberry Pi
y todo lo que trabaja a 5 V, y **dos baterías alcalinas de 9 V en paralelo** para el
puente H y los motores. Las dos fuentes no comparten ningún conductor.

---

## Por qué dos fuentes

La Raspberry Pi 4 requiere **5 V estables** y detecta caída de tensión (*undervoltage*)
por debajo de 4.63 V: reduce la frecuencia del SoC, corrompe la microSD y termina
reiniciándose. Alimentar la lógica y los motores del mismo punto mete el transitorio de
arranque de los motores —cinco a ocho veces la corriente nominal— directamente en el
riel de la Pi.

Con una fuente para cada dominio ese transitorio no tiene por dónde llegar: las tierras
`GND_LOG` y `GND_POT` quedan separadas desde la batería, no solo desde un regulador, y
las únicas señales que cruzan lo hacen por los optoacopladores (ver
[`hardware-aislamiento.md`](hardware-aislamiento.md)).

---

## Arquitectura

```
   ┌──────────────────┐                    ┌──────────────────────┐
   │  Power bank USB  │                    │ 2 × batería de 9 V   │
   │  5 V regulados   │                    │ alcalina, en paralelo│
   └────────┬─────────┘                    └──────────┬───────────┘
            │ USB-C                                   │ ~9 V
     DOMINIO LÓGICO                            DOMINIO DE POTENCIA
     5 V · GND_LOG                             9 V · GND_POT
            │                                         │
     ┌──────┴───────┐                          ┌──────┴───────┐
     │ Raspberry Pi │                          │ L298N  (VS)  │
     │      4       │                          │ regulador de │
     └──────┬───────┘                          │ 5 V interno  │
            │ pin de 5 V                       └──┬────────┬──┘
     ┌──────┴────────────┐                        │        │
     │ Servo del radar   │                 ┌──────┴───┐ ┌──┴───────────┐
     │ HC-SR04           │                 │ Motor izq│ │ +5V_POT:     │
     │ MPU-6050 (GY-521) │                 │ Motor der│ │ VSS y pull-up│
     │ PAM8403 + parlante│                 └──────────┘ │ de los optos │
     │ LEDs ×4 (GPIO)    │                              └──────────────┘
     └───────────────────┘

           ╳  GND_LOG y GND_POT NO se unen
              (ver docs/hardware-aislamiento.md)
```

---

## Dominio lógico: power bank

El power bank entrega 5 V ya regulados por su salida USB y trae de fábrica el circuito
de protección de su celda (sobrecarga, sobredescarga y cortocircuito). Por eso la
Raspberry Pi nunca queda conectada directamente a una celda de Li-Ion, que es lo que el
enunciado prohíbe, y el grupo no tuvo que armar ni ajustar un BMS ni un regulador.

La Raspberry Pi se alimenta por el **conector USB-C**, que pasa por la protección de
entrada de la tarjeta. Del **pin de 5 V** del conector de 40 pines salen el servo del
radar, el HC-SR04, el MPU-6050 y el amplificador con su parlante.

| Consumidor | Corriente típica | Pico |
|---|---|---|
| Raspberry Pi 4 (WiFi + CPU al 100 %) | 1.2 A | **2.5 A** |
| Servo del radar (SG90/MG90S) | 100–250 mA moviéndose | ~700 mA trabado |
| Amplificador PAM8403 + parlante de 8 Ω | 80 mA | 400 mA |
| HC-SR04 del radar | 15 mA | 20 mA |
| 4 × LED a 5 mA (nunca más de 3 encendidos) | 15 mA | 15 mA |
| 4 × LED de optoacoplador | 20 mA | 20 mA |
| MPU-6050 | 4 mA | 4 mA |
| **Total** | **~1.6 A** | **~3.7 A** |

El pico suma el peor caso de todo **a la vez**: la CPU al 100 %, el servo trabado y el
amplificador a volumen máximo sobre un golpe de bajo. En la práctica no coinciden.

El **servo es el consumidor delicado** de este dominio: es un motor, y sus picos y su
ruido entran al mismo riel de 5 V que alimenta la Raspberry Pi. Lo que lo mantiene
controlado:

- el barrido usa una rampa a un tercio de la velocidad del servo, así que no arranca de
  golpe en cada paso;
- conviene un capacitor de 470 µF en los bornes del servo, lo más cerca posible;
- si con música fuerte la Raspberry Pi marca subtensión, se baja el volumen máximo.

El MPU-6050 va en un módulo **GY-521**, que trae su propio regulador de 3.3 V y acepta
5 V en `VCC`; que el bus I2C siga en 3.3 V se comprueba midiendo `SDA` y `SCL` (ver
[`hardware-sensores.md`](hardware-sensores.md)).

---

## Dominio de potencia: dos baterías de 9 V

Dos baterías alcalinas de 9 V (las cuadradas, formato PP3) conectadas **en paralelo**:
la tensión sigue siendo de 9 V y la corriente se reparte entre las dos. Alimentan
directamente la entrada `VS` del L298N.

El L298N cae unos **2 V** entre `VS` y la salida por su topología de transistores
bipolares, así que los motores reciben cerca de **7 V**. Los motores son lentos y de alto
torque (60 rpm a 12 V), con rango de 6 a 12 V, y a esa tensión mueven el robot solo si la reciben
completa: por eso van a velocidad fija, sin PWM (ver
[`hardware-aislamiento.md`](hardware-aislamiento.md#velocidad-fija)).

`VSS` (los 5 V de la lógica interna del L298N) y los pull-up de los optoacopladores
salen del **regulador interno del módulo L298N**, con su jumper puesto, válido mientras
`VS ≤ 12 V`. **Nunca de los 5 V de la Raspberry Pi**: eso uniría las dos tierras y
anularía el aislamiento.

### Limitación: la autonomía

Una alcalina de 9 V tiene poca capacidad (del orden de 500 mAh) y una resistencia
interna alta: bajo la corriente de los motores su tensión cae y se agota pronto. Dos en
paralelo reparten la corriente y alargan la duración, pero siguen siendo la parte del
robot que primero se descarga. Para la demostración conviene llevar baterías de
repuesto (issue #34).

Al ser alcalinas no llevan BMS: no se recargan, y las dos deben ser **del mismo tipo y
estar igual de nuevas**, porque una gastada en paralelo con una nueva se descarga sobre
la otra.

---

## Desacople

| Dónde | Componente | Para qué |
|---|---|---|
| `VS` del L298N | 100 µF + 100 nF | Absorbe el pico de arranque de los motores |
| Bornes del servo | 470 µF / 10 V + 100 nF | Absorbe el pico de arranque en cada paso del barrido |
| El HC-SR04 | 100 nF | Ruido del pulso de disparo |
| `VDD` del PAM8403 | 100 µF + 100 nF | El clase D consume a pulsos |

Los electrolíticos van **con la polaridad correcta y lo más cerca posible del punto que
desacoplan**.

---

## Cableado

| Tramo | Calibre | Motivo |
|---|---|---|
| Baterías de 9 V → L298N → motores | **AWG 20** | Corriente de arranque |
| Power bank → Raspberry Pi | Cable USB-C corto y de buena calidad | La caída en el cable cuenta contra el margen de 4.63 V |
| Señales de sensores y LEDs | AWG 24 / Dupont | Corriente despreciable |

Los cables de motor van **trenzados entre sí** y separados de los cables de señal. Un
par trenzado cancela buena parte del campo magnético que de otro modo se acopla a las
líneas de `ECHO`.

---

## Lista de materiales

| Cantidad | Componente | Especificación |
|---|---|---|
| 1 | Power bank USB | Salida de 5 V, con su cable USB-C |
| 2 | Batería alcalina de 9 V | Del mismo tipo y estado, en paralelo |
| 2 | Broche para batería de 9 V | Con cables rojo y negro |
| 1 | Capacitor 470 µF / 10 V | Bornes del servo |
| 1 | Capacitor 100 µF / 25 V | `VS` del L298N |
| 2 | Capacitor 100 nF cerámico | Desacople |
| — | Cable AWG 20 | Rojo y negro |

---

## Verificación

### Paso 1 — Aislamiento entre dominios, todo desenergizado

| Entre | Esperado |
|---|---|
| `GND_LOG` y `GND_POT` | **Circuito abierto** |
| Pin de 5 V de la Raspberry Pi y `VS` del L298N | **Circuito abierto** |

### Paso 2 — Dominio de potencia solo

Con las baterías de 9 V conectadas y la Raspberry Pi apagada:

| Punto | Esperado |
|---|---|
| `VS` del L298N | Alrededor de 9 V con baterías nuevas |
| `+5V_POT` (salida de 5 V del L298N) | 5 V ± 0.25 V |
| Entradas `IN1`–`IN4` con los optos en reposo | ~5 V: los motores quedan frenados |

### Paso 3 — Ya con la Raspberry Pi encendida

Con el robot navegando y reproduciendo audio a la vez, que es el peor caso de consumo,
la Raspberry Pi no debe reiniciarse ni registrar subtensión:

```bash
dmesg | grep -i voltage        # no debe imprimir nada
```

---

## Estado

- [x] Topología definida: power bank para el dominio lógico y dos baterías de 9 V en paralelo para el de potencia
- [x] Servo, HC-SR04, MPU-6050 y amplificador en los 5 V de la Raspberry Pi
- [x] `VSS` y pull-up de los optos desde el regulador interno del L298N
- [x] Tierras separadas desde la fuente
- [x] Procedimiento de verificación
- [x] Robot armado y alimentado con esta topología

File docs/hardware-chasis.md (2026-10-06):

# Chasis y modelo físico

El modelo físico tiene rubro propio: se evalúa **funcionalidad y estética**. El chasis
es una carcasa circular impresa en 3D, de dos piezas que cierran a presión, sin
tornillos. Los archivos del diseño —modelo paramétrico, piezas para imprimir y vistas—
están en [`../modelo-3d/`](../modelo-3d/).

Carcasa armada

---

## Forma: circular

| | **Circular** | Rectangular |
|---|---|---|
| Girar en un espacio cerrado | Gira sobre su eje sin tocar nada | Las esquinas chocan al girar |
| Salir de un rincón | Rota y sale | Se puede trabar |
| Aprovechamiento del área interna | Menor | Mayor |
| Referencia visual | Es lo que la gente espera de una aspiradora | Parece un prototipo |

**Se eligió circular.** Con tracción diferencial y carcasa circular, el robot gira sobre
su propio centro sin barrer área adicional, así que cualquier rincón del que pueda
entrar es un rincón del que puede salir. Y es la silueta que se asocia a una aspiradora
robot.

---

## Dimensiones

| Parámetro | Valor | Motivo |
|---|---|---|
| Diámetro exterior | **215 mm** | El máximo que entra en la cama de la impresora (249 × 219 mm) |
| Altura de la carcasa | **45 mm** | Con las ruedas, el robot mide 53 mm desde el suelo |
| Separación al piso | **8 mm** | La que deja una rueda de 30 mm con el motor apoyado en el piso de la carcasa |
| Pieza inferior | 18 mm de alto | Piso de 2.0 mm y pared de 1.6 mm |
| Pieza superior | 43 mm de alto | Tapa y pared de 1.6 mm |
| Masa impresa | unos 265 g | Inferior 124 g, superior 125 g, dos ruedas 9 g, aro 4 g, boquilla 4 g |

Los espesores son bajos a propósito: la carcasa es lo que más pesa de lo impreso, y los
motores son lentos.

---
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

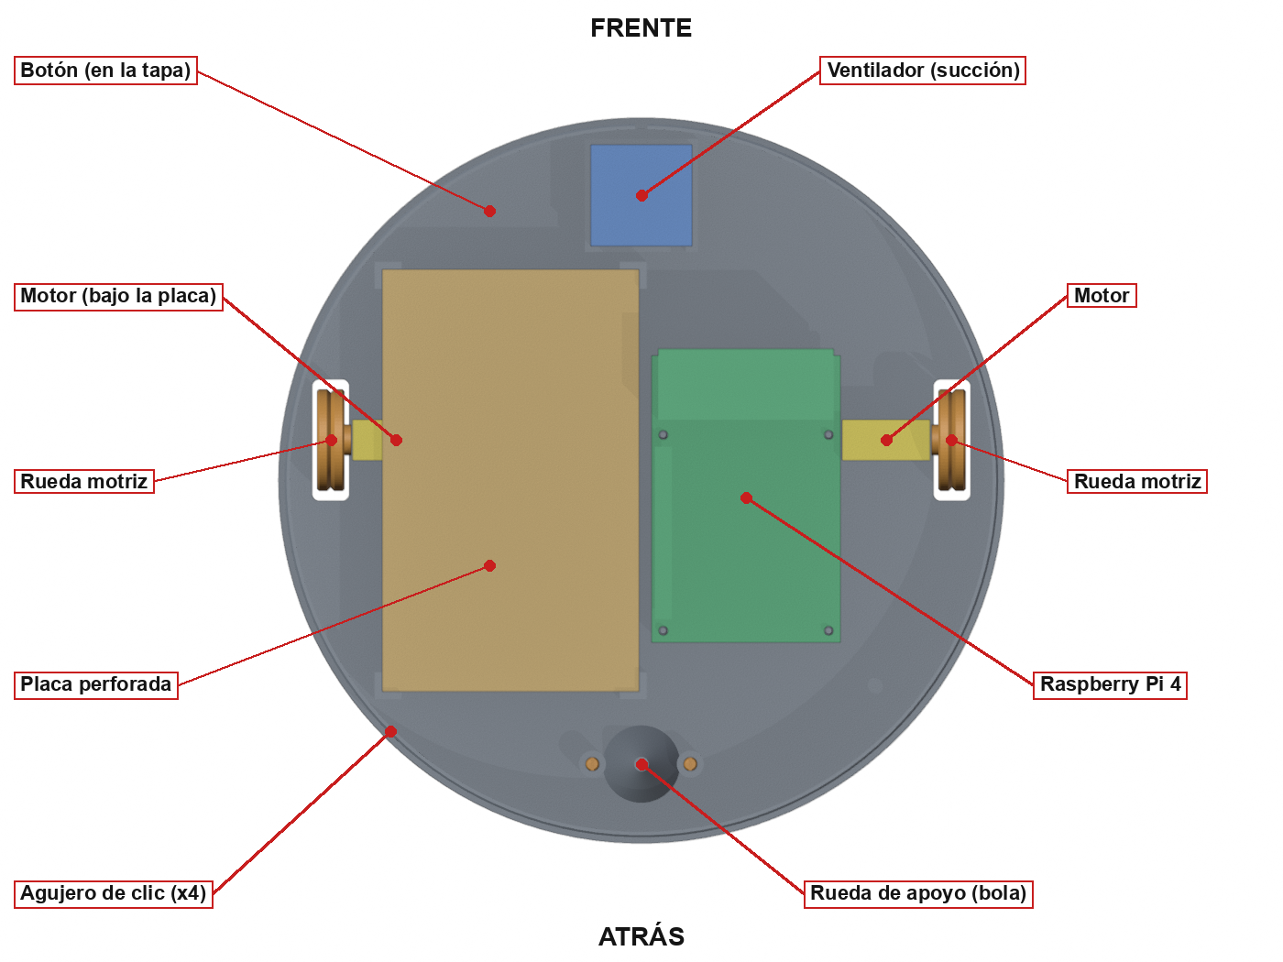
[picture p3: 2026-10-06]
modelo-3d/vistas/vista_1_distribucion.png

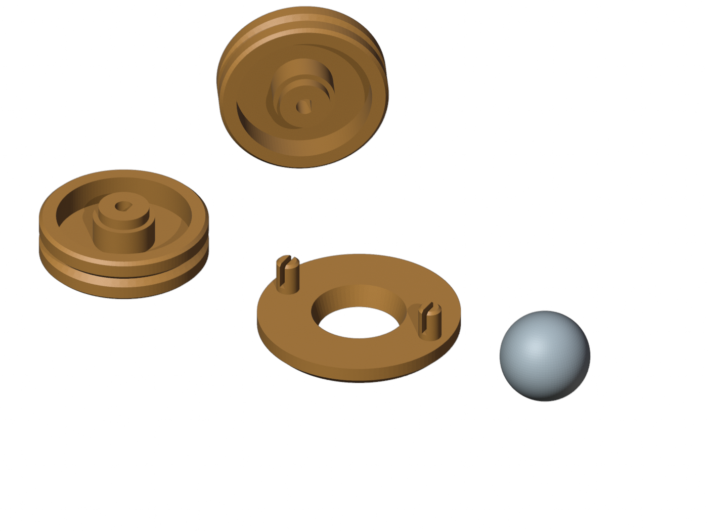
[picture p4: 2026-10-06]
modelo-3d/vistas/vista_7_ruedas.png

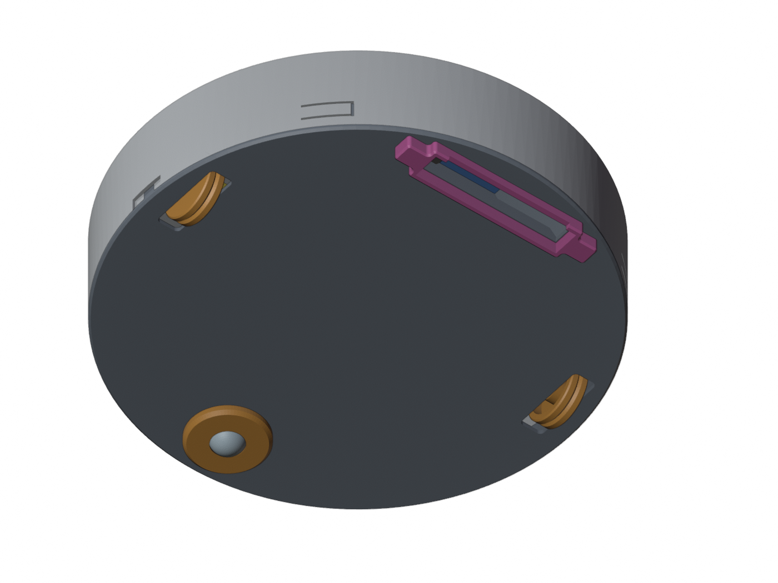
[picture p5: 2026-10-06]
modelo-3d/vistas/succion_4_por_debajo.png

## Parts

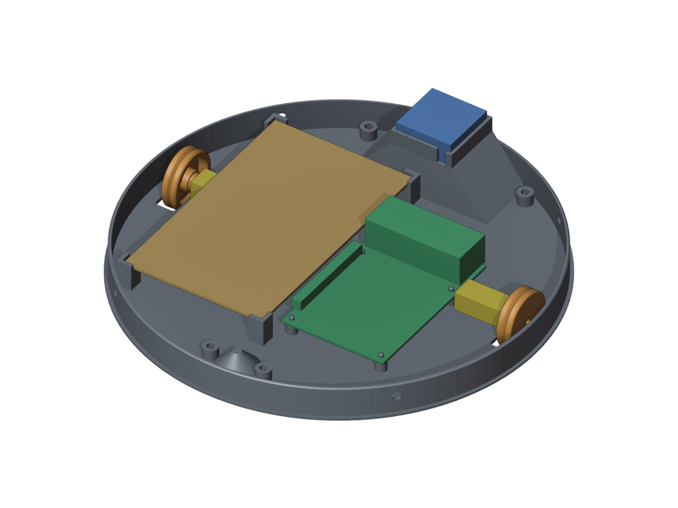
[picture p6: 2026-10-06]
modelo-3d/vistas/succion_2_con_componentes.png

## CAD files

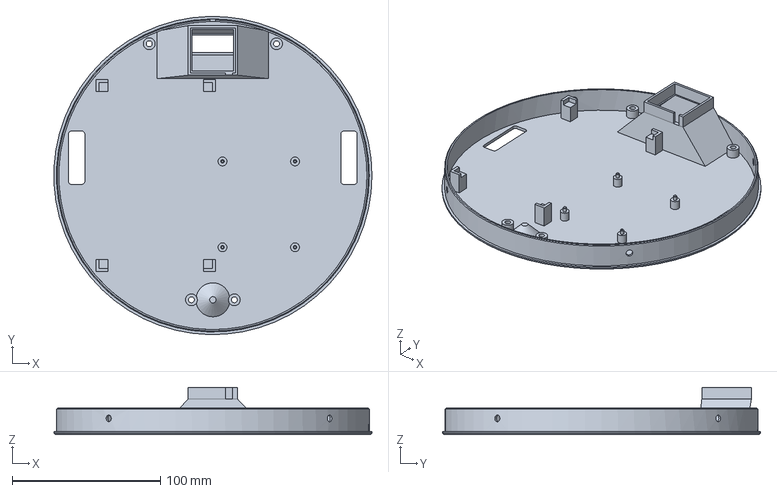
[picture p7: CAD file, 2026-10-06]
modelo-3d/carcasa_inferior_succion.step
214.8 x 214.9 x 32.0 mm

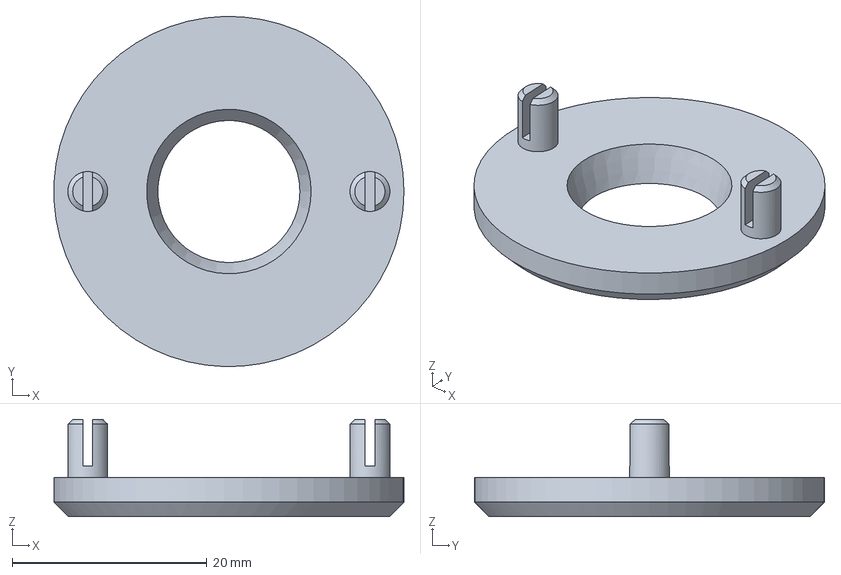
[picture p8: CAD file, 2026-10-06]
modelo-3d/rueda_apoyo_aro.step
36.0 x 36.0 x 10.0 mm

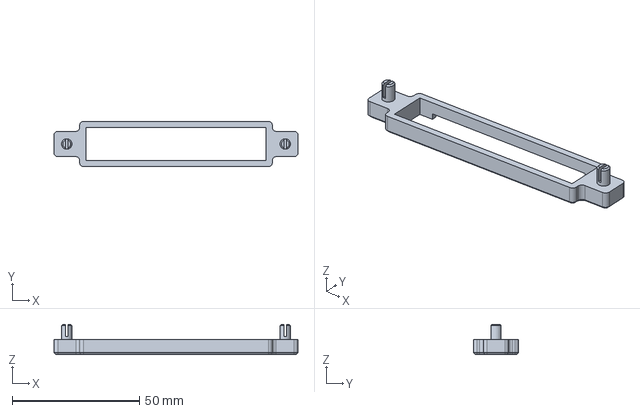
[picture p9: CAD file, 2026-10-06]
modelo-3d/boquilla_succion.step
96.0 x 17.8 x 12.0 mm

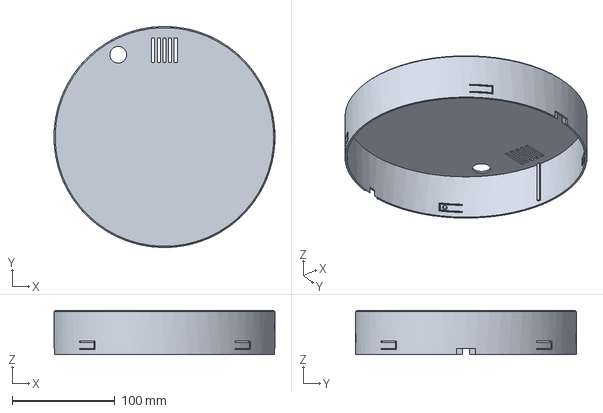
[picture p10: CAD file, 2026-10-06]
modelo-3d/carcasa_superior.step
215.0 x 215.0 x 43.0 mm

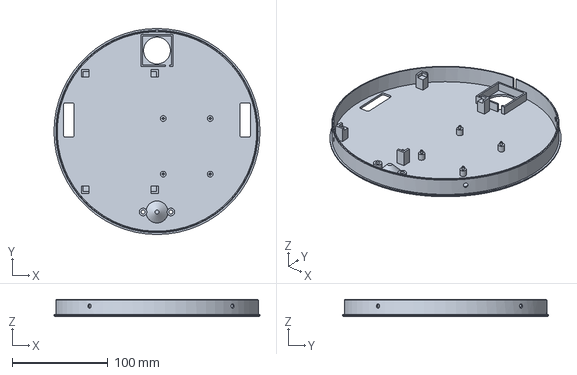
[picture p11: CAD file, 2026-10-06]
modelo-3d/carcasa_inferior.step
215.0 x 215.0 x 18.0 mm

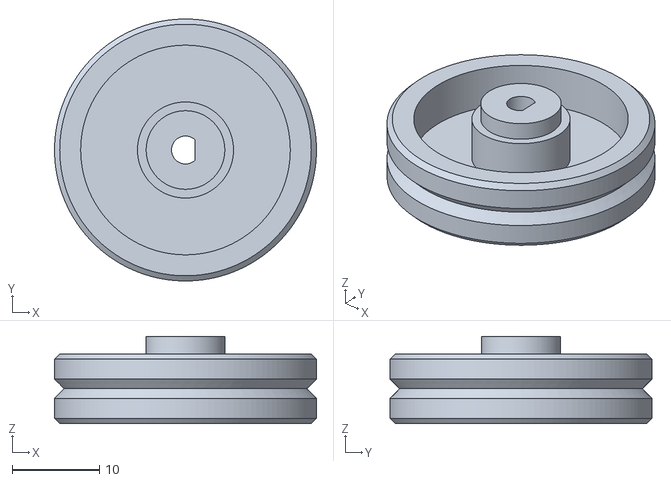
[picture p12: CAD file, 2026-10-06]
modelo-3d/rueda_motriz_x2.stl
30.0 x 30.0 x 10.0

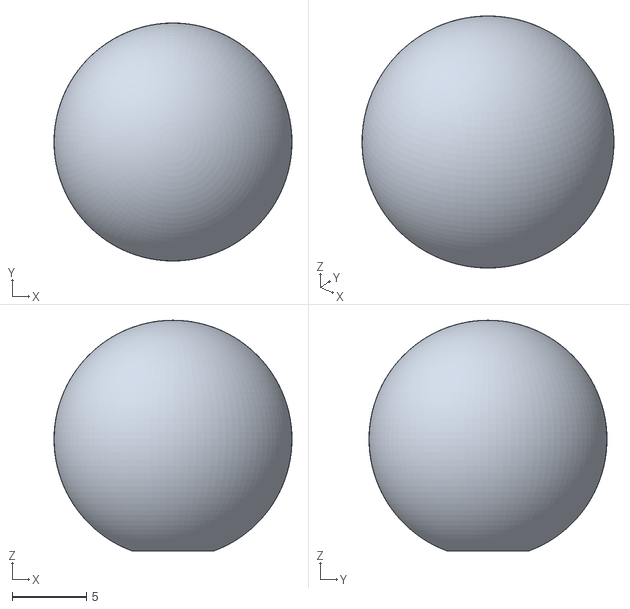
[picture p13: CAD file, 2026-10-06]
modelo-3d/rueda_apoyo_bola_16mm.stl
16.0 x 16.0 x 15.5

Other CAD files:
modelo-3d/rueda_motriz.step
modelo-3d/boquilla_succion.stl
modelo-3d/carcasa_inferior.stl
modelo-3d/carcasa_inferior_succion.stl
modelo-3d/carcasa_superior.stl
modelo-3d/rueda_apoyo_aro.stl

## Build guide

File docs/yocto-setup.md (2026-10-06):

# Construcción de la imagen con Yocto

Procedimiento completo, desde un host limpio hasta una Raspberry Pi 4 arrancando la
imagen del proyecto. Versión de Yocto: **Poky, rama `scarthgap` (LTS 5.0)**.

Todas las capas deben estar en la misma rama: mezclar `scarthgap` con `kirkstone` o
`walnascar` provoca errores de `LAYERSERIES_COMPAT` al parsear.

---

## 1. Preparación del host

Host de referencia: Ubuntu 22.04 / 24.04 o Debian 12, 64 bits.

```bash
sudo apt update
sudo apt install -y gawk wget git diffstat unzip texinfo gcc build-essential \
    chrpath socat cpio python3 python3-pip python3-pexpect xz-utils \
    debianutils iputils-ping python3-git python3-jinja2 python3-subunit \
    zstd liblz4-tool file locales libacl1 bmap-tools
sudo locale-gen en_US.UTF-8
```

Requisitos de recursos, medidos en el build de referencia:

| Recurso | Mínimo | Recomendado |
|---|---|---|
| Espacio en disco | 100 GB | 150 GB (con `rm_work` activo) |
| RAM | 8 GB | 16 GB |
| Tiempo del primer build | más de 5 h | menos con más núcleos |

> **La RAM es el límite real, no el disco.** En el host del grupo (4 núcleos, 7 GB) un
> build con `BB_NUMBER_THREADS = "3"` agotó los 4 GB de swap y colgó la máquina al 67 %
> del progreso: coincidieron el `do_fetch` del kernel de la Raspberry Pi, el
> `do_compile` de `binutils` y un `do_configure`. No hubo ningún error de receta.
>
> En máquinas de 8 GB o menos hay que bajar a 2 hilos **y** activar la regulación por
> presión de recursos. Ver la sección [Hosts con poca memoria](#hosts-con-poca-memoria).

> El build **no** debe hacerse sobre un sistema de archivos NTFS, exFAT ni sobre un
> directorio de red: BitBake necesita permisos POSIX y enlaces simbólicos.

---

## 2. Clonar Poky y las capas

Todo se clona dentro de un mismo directorio de trabajo, junto al repositorio del
proyecto:

```bash
mkdir -p ~/yocto && cd ~/yocto

git clone -b scarthgap https://git.yoctoproject.org/poky.git
cd poky
git clone -b scarthgap https://github.com/agherzan/meta-raspberrypi.git
git clone -b scarthgap https://github.com/openembedded/meta-openembedded.git
cd ..

# Repositorio del proyecto: aporta la capa meta-robot/
git clone https://github.com/Randall-BL/EmpotradosProyecto1.git
```

| Capa | Para qué |
|---|---|
| `poky/meta`, `meta-poky`, `meta-yocto-bsp` | Núcleo de OpenEmbedded y la distro `poky` |
| `meta-raspberrypi` | BSP de la Raspberry Pi 4: kernel, bootloader, firmware, `config.txt` |
| `meta-openembedded/meta-oe` | Utilidades base y dependencias comunes |
| `meta-openembedded/meta-python` | Dependencias Python de otras recetas |
| `meta-openembedded/meta-multimedia` | `mpg123` (decodificador MP3) |
| `meta-openembedded/meta-networking` | Utilidades de red |
| `EmpotradosProyecto1/meta-robot` | Capa propia: `librobot`, `robot-server`, imagen y configuración |

---

## 3. Inicializar el entorno de build

```bash
cd ~/yocto/poky
source oe-init-build-env          # crea build/ y deja la shell dentro
```

Este comando genera `build/conf/local.conf` y `build/conf/bblayers.conf`. Ninguno de
los dos se versiona: contienen rutas absolutas propias de cada máquina.

---

## 4. Registrar las capas

```bash
bitbake-layers add-layer ../meta-raspberrypi
bitbake-layers add-layer ../meta-openembedded/meta-oe
bitbake-layers add-layer ../meta-openembedded/meta-python
bitbake-layers add-layer ../meta-openembedded/meta-multimedia
bitbake-layers add-layer ../meta-openembedded/meta-networking
bitbake-layers add-layer ~/yocto/EmpotradosProyecto1/meta-robot

bitbake-layers show-layers        # verificar que aparezcan las 8 capas
```

> **`meta-robot` debe agregarse desde su ubicación dentro del repositorio clonado**, no
> copiarse suelta al directorio de Poky. Las recetas `librobot` y `robot-server` toman
> sus fuentes de `lib/`, `server/` y `audio/`, que están en la raíz del repositorio, vía
> `FILESEXTRAPATHS`. Si se mueve solo la carpeta `meta-robot/`, el `do_fetch` falla.

---

## 5. Configurar `local.conf`

Anexe al final de `build/conf/local.conf` el contenido de
[`meta-robot/conf/local.conf.sample`](../meta-robot/conf/local.conf.sample):

```bash
cat ~/yocto/EmpotradosProyecto1/meta-robot/conf/local.conf.sample >> conf/local.conf
```

Ese archivo lleva comentada la razón de cada variable. Lo esencial:

```
MACHINE = "raspberrypi4-64"
DISTRO_FEATURES:append = " systemd usrmerge wifi"
VIRTUAL-RUNTIME_init_manager = "systemd"
LICENSE_FLAGS_ACCEPTED = "synaptics-killswitch"
DISABLE_VC4GRAPHICS = "1"
ENABLE_I2C = "1"
RPI_KERNEL_DEVICETREE_OVERLAYS:append:rpi = " overlays/audremap.dtbo"
```

Las dos últimas son del hardware del radar y del audio: el bus I2C del MPU-6050 y el
overlay que saca el audio por GPIO 18 hacia el PAM8403 (ver
[`hardware-sensores.md`](hardware-sensores.md)). **Si su `build/conf/local.conf` es
anterior a ese cambio**, agregue esas dos líneas y `i2c-dev` a
`KERNEL_MODULE_AUTOLOAD` —o vuelva a copiar el bloque—. Sin el overlay, el firmware
ignora la línea de `config.txt` y el audio sale por el jack, que no está conectado.
Cambiar la lista de overlays recompila el kernel una vez.

Ajuste `BB_NUMBER_THREADS` y `PARALLEL_MAKE` al host — pero al número de núcleos **y** a
la RAM, no solo a los núcleos:

| RAM del host | `BB_NUMBER_THREADS` |
|---|---|
| ≥ 16 GB | un hilo por núcleo |
| 8–16 GB | la mitad de los núcleos |
| ≤ 8 GB | 2, más la regulación por presión |

### Hosts con poca memoria

Cada tarea de compilación pesada —`gcc-cross`, `binutils`, `glibc`, el kernel— puede
pedir cerca de 2 GB. Con tres corriendo a la vez en una máquina de 7 GB, el sistema entra
en *thrashing* de swap y se cuelga sin emitir un solo error: bitbake reporta
`Bitbake still alive (no events for 3000s)` y termina perdiendo contacto con su servidor.

La defensa es la regulación por presión de recursos, que necesita PSI en el kernel:

```bash
ls /proc/pressure/          # deben aparecer cpu, io y memory
```

Y en `build/conf/local.conf`:

```
BB_NUMBER_THREADS = "2"
PARALLEL_MAKE = "-j 2"

BB_PRESSURE_MAX_MEMORY = "5000"
BB_PRESSURE_MAX_IO     = "15000"
```

Los valores son microsegundos de bloqueo por segundo: mientras la presión los supere,
bitbake **no lanza tareas nuevas**. Limitar los hilos acota el caso promedio; esto acota
el pico, que es lo que en la práctica tumba la máquina.

### `do_fetch` del kernel falla con "Unable to find revision"

Síntoma:

```
ERROR: linux-raspberrypi-1_6.6.63+git-r0 do_fetch: Fetcher failure:
  Unable to find revision e442e5c1ab6bff5b5460b4fc949beb72aaf77970
  in branch rpi-6.6.y even from upstream
```

El mensaje miente: la revisión **sí está** en el mirror local y **sí es alcanzable**
desde la rama. Compruébelo:

```bash
M=build/downloads/git2/github.com.raspberrypi.linux.git
git --git-dir=$M cat-file -e <SRCREV>                              # existe
git --git-dir=$M merge-base --is-ancestor <SRCREV> refs/heads/rpi-6.6.y  # alcanzable
```

**Causa real.** BitBake comprueba la alcanzabilidad así:

```bash
git branch --contains <SRCREV> --list rpi-6.6.y 2> /dev/null | wc -l
```

Manda el `stderr` a `/dev/null` y cuenta líneas. En el mirror bare, BitBake deja
`HEAD` apuntando a `refs/heads/.invalid` a propósito, para que nadie haga un checkout
accidental. **Git 2.4x aborta `git branch` cuando `HEAD` no resuelve**:

```
fatal: failed to resolve HEAD as a valid ref
```

Las versiones de git con las que se validó `scarthgap` lo toleraban. Como BitBake
descarta el `stderr`, el fallo real queda oculto y `wc -l` devuelve 0, que BitBake
interpreta como "la revisión no existe". De ahí el mensaje engañoso.

Es un choque entre `scarthgap` y el git de las distribuciones nuevas — el mismo motivo
del aviso `Host distribution "ubuntu-25.04" has not been validated`.

**Solución.** Apuntar `HEAD` del mirror a una rama real:

```bash
M=build/downloads/git2/github.com.raspberrypi.linux.git
git --git-dir=$M symbolic-ref HEAD refs/heads/rpi-6.6.y

# Verificar que la comprobación de BitBake ya pasa: debe imprimir 1
git --git-dir=$M branch --contains <SRCREV> --list rpi-6.6.y | wc -l
```

Y relanzar `bitbake robot-image`.

> Diagnóstico general: cuando BitBake diga que una revisión no existe, **ejecute a mano
> el comando que aparece en `temp/log.do_fetch.*` sin el `2> /dev/null`**. El log de
> depuración trae la línea exacta, y el error verdadero suele estar en ese `stderr`
> descartado.

### Si el build se cuelga

No se pierde nada. Yocto guarda el trabajo terminado en `sstate-cache/`, así que al
relanzar `bitbake robot-image` retoma desde donde quedó en vez de empezar de cero. Basta
con bajar el paralelismo y volver a lanzarlo.

---

## 6. Credenciales de WiFi

El arranque es headless: el robot debe conectarse solo a la red. Cree el archivo de
credenciales (está en `.gitignore`, nunca se sube al repositorio):

```bash
cd ~/yocto/EmpotradosProyecto1
cp meta-robot/recipes-connectivity/wifi-config/files/wpa_supplicant-wlan0.conf.sample \
   meta-robot/recipes-connectivity/wifi-config/files/wpa_supplicant-wlan0.conf
$EDITOR meta-robot/recipes-connectivity/wifi-config/files/wpa_supplicant-wlan0.conf
```

Después de cambiar las credenciales hay que invalidar el estado en caché de esa receta:

```bash
bitbake -c cleansstate wifi-config && bitbake robot-image
```

> **Si se omite este paso la imagen se construye igual.** La receta `wifi-config` cae a
> la plantilla cuando no encuentra el archivo real, para que un clon limpio del
> repositorio produzca la imagen sin pasos manuales previos —que es el requisito de
> reproducibilidad del enunciado. En ese caso bitbake emite un `WARNING` explícito y el
> robot arranca pero **no se conecta a la red**, así que hay que revisar el log del
> build antes de dar por buena la imagen.

---

## 7. Construir

Primero una imagen mínima, para validar que el BSP, el WiFi y el audio funcionan antes
de meter el software del robot:

```bash
bitbake core-image-minimal
```

Luego la imagen completa del proyecto:

```bash
bitbake robot-image
```

El resultado queda en:

```
tmp/deploy/images/raspberrypi4-64/robot-image-raspberrypi4-64.rootfs.wic.bz2
```

---

## 8. Grabar la microSD

```bash
cd tmp/deploy/images/raspberrypi4-64/
bzip2 -dk robot-image-raspberrypi4-64.rootfs.wic.bz2
lsblk                              # identificar el dispositivo, p. ej. /dev/sdb
sudo bmaptool copy --nobmap robot-image-raspberrypi4-64.rootfs.wic /dev/sdX
sync
```

> Verifique el dispositivo con `lsblk` **antes** de ejecutar `bmaptool`. Escribir sobre
> el disco equivocado destruye el sistema del host.

La SD queda con tres particiones (`meta-robot/wic/robot-sdimage.wks`), ninguna de más
de 200 MB:

| Partición | Montaje | Tipo | Tamaño | Contenido |
|---|---|---|---|---|
| p1 `boot` | `/boot` | vfat | 130 MiB | firmware, kernel, DTBs |
| p2 `root` | `/` | ext4 | 180 MiB | rootfs sin las canciones |
| p3 `canciones` | `/opt/robot/audio/canciones` | ext4 | 180 MiB | la playlist |

---

## 9. Primer arranque

1. Inserte la microSD y alimente la Raspberry Pi 4.
2. Consola serie por UART (115200 8N1) o SSH una vez que tome IP:
   ```bash
   ssh root@<ip-del-robot>
   ```
3. Verificaciones en el target:
   ```bash
   uname -a                          # kernel y arquitectura aarch64
   ip a                              # wlan0 con IP asignada
   aplay -l                          # tarjeta de audio detectada (card 1)
   ls /dev/i2c-1                     # bus I2C del MPU-6050
   systemctl status robot-server     # servicio activo
   ls /usr/lib/librobot.so*          # biblioteca dinamica instalada
   ```

---

## 10. Verificación del rootfs antes de flashear

Permite detectar módulos o firmware faltantes sin gastar un ciclo de escritura y
arranque:

```bash
ROOTFS=tmp/work/raspberrypi4_64-poky-linux/robot-image/1.0/rootfs

echo "=== Modulos Broadcom (WiFi) ==="
find $ROOTFS/usr/lib/modules -name "*.ko.xz" | grep brcm | sort

echo "=== Modulos de sonido ==="
find $ROOTFS/usr/lib/modules -name "*.ko.xz" | grep snd | sort

echo "=== Modulos I2C (MPU-6050) ==="
find $ROOTFS/usr/lib/modules -name "*.ko.xz" | grep -E "i2c-dev|i2c-bcm2835" | sort

echo "=== Audio por GPIO 18 e I2C en config.txt, y el overlay ==="
DEPLOY=tmp/deploy/images/raspberrypi4-64
grep -E "^ *(dtoverlay=audremap|dtparam=i2c_arm=on)" $DEPLOY/bootfiles/config.txt
ls $DEPLOY/audremap.dtbo

echo "=== Firmware WiFi ==="
ls $ROOTFS/lib/firmware/brcm/ | grep 43455

echo "=== Servicios habilitados en el arranque ==="
ls -la $ROOTFS/etc/systemd/system/multi-user.target.wants/

echo "=== Configuracion ALSA ==="
cat $ROOTFS/etc/asound.conf

echo "=== Biblioteca dinamica ==="
find $ROOTFS/usr/lib -name "librobot*"
```

Y el manifiesto de paquetes de la imagen:

```bash
grep -E "librobot|robot-server|pigpio|mpg123" \
  tmp/deploy/images/raspberrypi4-64/robot-image-raspberrypi4-64.rootfs.manifest
```

---

## 11. Comandos de mantenimiento

| Comando | Para qué |
|---|---|
| `bitbake -c cleansstate <receta>` | Fuerza la reconstrucción de una receta ignorando la caché sstate |
| `bitbake -c menuconfig virtual/kernel` | Menú de configuración del kernel |
| `bitbake -e <receta> \| grep ^VARIABLE=` | Muestra el valor final de una variable |
| `bitbake-layers show-recipes <nombre>` | Indica qué capa provee una receta |
| `oe-pkgdata-util list-pkgs \| grep <patrón>` | Busca el nombre exacto de un paquete |
| `bitbake -g robot-image` | Genera el grafo de dependencias de la imagen |

### Nombres de los módulos de kernel

Los paquetes `kernel-module-*` llevan la versión del kernel en el nombre, y esa versión
cambia al actualizar `meta-raspberrypi`. Si `bitbake robot-image` falla con
`Nothing PROVIDES kernel-module-...`, hay que averiguar el nombre vigente:

```bash
bitbake -e virtual/kernel | grep "^PACKAGES"
oe-pkgdata-util list-pkgs | grep brcm
oe-pkgdata-util list-pkgs | grep snd
```

y actualizar los nombres en `meta-robot/recipes-image/images/robot-image.bb`.
El build de referencia usó el kernel **6.6.63-v8**.

---

## Estado

- [x] Dependencias del host documentadas
- [x] Capas y ramas compatibles definidas (`scarthgap`)
- [x] `local.conf` del proyecto versionado como `local.conf.sample`
- [x] Procedimiento de build, grabado y verificación documentado
- [x] Imagen construida y arrancada en la Raspberry Pi 4 — [`evidencias/ejecucion-target.md`](evidencias/ejecucion-target.md)

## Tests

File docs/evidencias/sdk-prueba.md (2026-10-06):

# Evidencia — Toolchain-SDK generado y probado

Complementa `docs/sdk.md` (el procedimiento) con la prueba real de que el SDK
se genera, se instala y **compila para ARM** en una máquina del grupo, sin la
Raspberry. Cubre el issue #8.

## 1. Generación

```
bitbake -c populate_sdk robot-image
```

Instalador producido en `tmp/deploy/sdk/`:

```
poky-glibc-x86_64-robot-image-cortexa72-raspberrypi4-64-toolchain-5.0.20.sh   264 MB
```

## 2. Instalación

Se instala sin privilegios de root, en el `$HOME` del desarrollador:

```
./poky-glibc-x86_64-...-toolchain-5.0.20.sh -y -d ~/robot-sdk
```

Tamaño instalado: 1,8G.

> Nota: si el perfil del host tiene `LD_LIBRARY_PATH` definido (p. ej. por
> OpenMPI), hay que `unset LD_LIBRARY_PATH` antes de cargar el entorno del SDK;
> el propio script del SDK lo advierte.

## 3. Prueba de compilación cruzada

```console
$ unset LD_LIBRARY_PATH
$ . ~/robot-sdk/environment-setup-cortexa72-poky-linux
$ echo $CC
aarch64-poky-linux-gcc  -mcpu=cortex-a72+crc  -fstack-protector-strong ...  --sysroot=.../sysroots/cortexa72-poky-linux

$ $CC hola_sdk.c -o hola_sdk
$ file hola_sdk
hola_sdk: ELF 64-bit LSB pie executable, ARM aarch64, version 1 (SYSV),
          dynamically linked, interpreter /lib/ld-linux-aarch64.so.1, ...

$ ./hola_sdk
bash: ./hola_sdk: no se puede ejecutar fichero binario: Formato de ejecutable incorrecto
```

El binario es **ARM aarch64** y **no corre en el host x86** — la prueba
objetiva de que el SDK cross-compila para la Raspberry Pi 4 y de que ningún
binario se construye de forma nativa en el target.

## Estado

- [x] `bitbake -c populate_sdk` genera el instalador
- [x] Instalado y probado en una máquina del grupo (esta laptop)
- [x] Verificado que compila para ARM y no para el host (`file` + fallo de ejecución en x86)
- [x] Procedimiento documentado (`docs/sdk.md` + esta evidencia)

La ejecución en el target real está en [`ejecucion-target.md`](ejecucion-target.md).

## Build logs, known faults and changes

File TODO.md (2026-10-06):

# TODO — Proyecto I: Robot Aspiradora Autónomo (Yocto)

**Curso:** CE-1113 Sistemas Empotrados — TEC
**Plataforma:** Raspberry Pi 4 + imagen Linux mínima construida con Yocto
**Fecha de entrega:** 6 de octubre de 2026
**Grupo:** 4 personas

> Leyenda: `[ ]` pendiente · `[~]` en progreso · `[x]` hecho
>
> En las secciones de software, `[x]` significa **implementado y verificado sin la
> Raspberry** (compilación cruzada con BitBake y/o prueba en el simulador `sim/`);
> `[~]` es lo que ya está en código pero **necesita el kit para validarse**. La
> confirmación final de todo el software depende de la demo en hardware.
> **(OBL)** obligatorio · **(OPC)** opcional · **(EVID)** genera evidencia que debe subirse al repositorio

---

## 0. Arranque del proyecto

- [x] Definir roles del grupo (navegación / audio / web+red / Yocto+integración)
- [x] Crear cronograma con hitos hasta el 6 de octubre de 2026
- [ ] Inventariar el kit entregado por el profesor (Raspberry Pi 4, sensores, motores, etc.)
- [x] Definir la arquitectura general del sistema (HW + SW) antes de escribir código
- [x] Acordar convenciones de código (estilo, nombres, estructura de carpetas)

---

## 1. Repositorio y flujo de trabajo Git — 10%

- [x] Inicializar repositorio Git y estructura de directorios del proyecto
- [x] Configurar ramas `main` / `develop` / `feature/*` (Git Flow o GitHub Flow)
- [x] Proteger `main` (merge solo vía Pull Request)
- [x] Adoptar **Conventional Commits** en todo el historial (`feat:`, `fix:`, `docs:`, `chore:`…) — ver `CONTRIBUTING.md`
- [x] Crear **issues** para planeamiento y seguimiento de tareas y bugs
- [x] Vincular commits y PRs a sus issues correspondientes
- [x] Agregar `.gitignore` (build/, tmp/, sstate-cache/, *.o, *.so, artefactos de Yocto)
- [~] Verificar que el historial tenga commits descriptivos y distribuidos en el tiempo (no un único commit final)

---

## 2. Hardware — modelo físico y circuitería

### 2.1 Modelo físico
- [x] Diseñar el chasis (circular o rectangular) — se evalúa funcionalidad **y estética** — carcasa circular de 215 mm impresa en 3D, `modelo-3d/` y `docs/hardware-chasis.md`
- [x] Montar 2 motores DC con sus llantas + rueda loca de apoyo — ruedas impresas de 30 mm y bola de 16 mm
- [x] Montar el radar: HC-SR04 sobre el servo de 180° — `docs/hardware-sensores.md`
- [x] Montar el MPU-6050 plano y firme, con X hacia el frente
- [x] Montar los 4 LEDs indicadores en posición visible
- [x] Montar el parlante y el amplificador PAM8403 con su filtro RC — `docs/hardware-sensores.md`
- [x] Montar la fuente de alimentación portátil a bordo
- [ ] Asegurar el cableado (ruteo limpio, sin cables sueltos que estorben el movimiento)

### 2.2 Seguridad eléctrica — **LECTURA OBLIGATORIA DEL ENUNCIADO**

> El incumplimiento puede dañar permanentemente el equipo prestado por el curso; la responsabilidad es del grupo.

- [x] **Aislamiento galvánico u óptico obligatorio** entre la lógica (3.3 V) y la etapa de potencia
  - [x] Optoacopladores (PC817 / 4N25) en las señales PWM, **o**
  - [ ] Driver con aislamiento integrado (L298N con optos adicionales, DRV8871) — **verificar** que la entrada opere a 3.3/5 V y que la potencia tenga alimentación independiente
- [x] **Tierras separadas**: GND de lógica y GND de potencia unidas únicamente a través del aislador
- [x] Fuente portátil: power bank USB para la Raspberry Pi y dos baterías alcalinas de 9 V en paralelo para los motores — `docs/hardware-alimentacion.md`
- [x] **Protección de la celda de Li-Ion** (sobredescarga / sobrecarga / cortocircuito) — la trae integrada el power bank; las alcalinas no llevan BMS
- [x] 5 V regulados para la Raspberry Pi — los entrega el power bank por USB-C
- [x] **Dos rieles de alimentación independientes**: lógica (Pi, servo, sensores, LEDs, audio) desde el power bank y potencia (motores) desde las baterías de 9 V
- [x] Servo del radar alimentado de los 5 V de la Raspberry Pi, con la señal directa del GPIO 25 — `docs/hardware-aislamiento.md`
- [x] Probar cada riel con multímetro **antes** de conectar la Raspberry Pi — todas las verificaciones pasaron (sección 5.3 del DI)
- [x] Documentar el diagrama eléctrico completo (para el README y el documento DI) — `documentación/hardware-diagramas.pdf`

---

## 3. Sistema operativo mínimo con Yocto — (OBL)

- [x] Preparar el host de desarrollo (Ubuntu/Debian) con las dependencias de Yocto — documentado en `docs/yocto-setup.md` y ejecutado (la imagen se construyó)
- [x] Clonar Poky + `meta-raspberrypi` + `meta-openembedded` (rama `scarthgap`) — clonadas y en uso en el build
- [x] Configurar `local.conf` con `MACHINE = "raspberrypi4-64"` — versionado como `meta-robot/conf/local.conf.sample`
- [x] Construir la imagen base y arrancarla exitosamente en la Raspberry Pi 4 — imagen construida (rootfs 129 MB) y arrancada en la Pi: `docs/evidencias/ejecucion-target.md`
- [x] Generar el **Toolchain-SDK** para desarrollo cruzado ARM (`bitbake -c populate_sdk`) — instalador de 264 MB generado en `tmp/deploy/sdk`; documentado en `docs/sdk.md`
- [x] Verificar que **todo** el software se compila en el host y se ejecuta en el target — compilación cruzada y ejecución en la Pi verificadas: `docs/evidencias/`
- [x] Incluir **únicamente** los paquetes estrictamente necesarios (servidor web, bibliotecas de audio, decodificador MP3, GPIO)
- [x] Documentar y **justificar cada paquete** agregado más allá de la imagen mínima base — `docs/paquetes.md`

### 3.1 Capa y receta propia — (OBL) (EVID)
- [x] Crear la capa **`meta-robot/`** con su `conf/layer.conf`
- [x] Escribir al menos **una receta BitBake `.bb`** que integre la biblioteca dinámica y/o el servidor web
  - [x] `SRC_URI` que descargue o copie las fuentes
  - [x] Invocar CMake/Autotools con la toolchain de Yocto (`inherit cmake` / `autotools`)
  - [x] Instalar los artefactos en la imagen (`do_install`)
  - [x] Declarar **todas** las dependencias (`DEPENDS` / `RDEPENDS`)
  - [x] Instalar y habilitar la unidad systemd (`inherit systemd`, `SYSTEMD_SERVICE`)
- [~] **Validar la reproducibilidad desde cero**: `bitbake <imagen>` produce la imagen — reproduce la imagen sin pasos manuales; falta validarla en una **máquina limpia**
- [x] **(EVID)** Commitear el directorio `meta-robot/` con la receta y el `layer.conf`
- [x] **(EVID)** Guardar el fragmento de `log.do_compile` que confirme la compilación cruzada exitosa — en `docs/evidencias/`
- [x] **(EVID)** Capturas de pantalla o salida de terminal del binario ejecutándose en el target — `docs/evidencias/ejecucion-target.md`

---

## 4. Biblioteca dinámica de control (`.so`) — (OBL)

- [x] Definir la API pública de la biblioteca (header + versionado)
- [x] Configurar el build con **CMake o Autotools** y compilación cruzada ARM
- [x] Generar el **paquete estándar de código abierto** correspondiente
- [x] Implementar el módulo de **motores (PWM)**: avance, retroceso, giro izquierda/derecha, detención, velocidad por motor — con control diferencial (`motores_set`); L298N siempre habilitado (jumpers `ENA`/`ENB`) y la inversión del PC817 compensada. **A velocidad fija, sin PWM**: desviación acordada con el profesor (`MOTOR_VELOCIDAD_VARIABLE` en 0, en `lib_motors.h`; ver `docs/hardware-aislamiento.md`)
- [x] Implementar el módulo de **sensores de proximidad (GPIO)**: lectura en tiempo real — radar con servo en `lib_radar` + `lib_servo`
- [x] Implementar el módulo del **MPU-6050 (I2C)**: aceleración de avance y giro, con calibración — `lib_imu`
- [x] Implementar el módulo de **LEDs (GPIO)**: control de los 4 indicadores
- [x] Implementar el módulo de **reproducción de audio**
- [x] Manejo de errores y liberación segura de los recursos GPIO (init/cleanup)
- [x] **Verificar que el servidor web use exclusivamente esta biblioteca** para tocar hardware — se eliminó `robot_hardware.c`; `readelf` confirma que el servidor ya no enlaza pigpio
- [x] Documentar la API completa (para el README) — `docs/api-librobot.md`
- [x] Programa de prueba independiente que ejercite cada función de la biblioteca — `sim/prueba_librobot`, 47/47 comprobaciones

---

## 5. Navegación autónoma — (OBL)

- [~] Implementar el **modo autónomo** con al menos un algoritmo de cobertura reactiva — reactivo con rebote implementado y probado en el simulador; falta **prueba de campo**
- [x] Comportamiento ante obstáculo: **detenerse → retroceder → cambiar de dirección** automáticamente
- [x] Detección **frontal y lateral**: radar con un HC-SR04 sobre un servo de 180°, 7 direcciones (mont. físico en §2)
- [x] Confirmado con el profesor: el radar y el MPU-6050 bastan para "**al menos dos sensores**" (desviación acordada); no se monta un 2.º HC-SR04
- [x] Lectura y procesamiento de sensores **en tiempo real** — ~10 lecturas/s, frente cada ~0.6 s; `docs/navegacion-radar.md`
- [x] **Velocidad con el MPU-6050** y **tiempo antes de chocar**, actualizado en cada lectura frontal y proyectado entre lecturas — probado en el simulador
- [x] Evasión: retroceder, barrido completo y giro en lazo cerrado hacia el lado más libre — 2 min en el simulador, 14 evasiones y ningún choque
- [x] **Control diferencial** de los 2 motores DC vía PWM (giros con radio variable) — `motores_set` / `motores_curva` implementados y probados en el simulador; en el robot la velocidad es fija, sin PWM, por desviación acordada con el profesor: gira sobre su eje, una llanta adelante y la otra atrás
- [ ] Calibrar velocidades, umbrales (distancia y tiempo de choque), pulsos del servo y montaje del MPU — `docs/odometria.md`
- [x] **4 LEDs indicadores**: (1) modo autónomo activo, (2) modo manual activo, (3) alerta de obstáculo detectado, (4) sistema encendido — control en código
- [x] Implementar la **odometría** (insumo necesario para el mapa) — `lib_odom` con MPU-6050 + modelo de motores: 5 % de error de posición y 0.4° de rumbo en el simulador; **calibrar en campo**
- [ ] Prueba de campo: navegar un área definida sin colisiones ni bloqueos

---

## 6. Reproducción de audio MP3 — (OBL)

- [x] Reproducir archivos **MP3 almacenados localmente** en el sistema de archivos
- [x] Reproducción **concurrente con la navegación** (proceso o hilo independiente)
- [~] Salida de audio física: PWM por GPIO 18 (`audremap`) → filtro RC → **PAM8403** → parlante, mezclado a mono — configurado en la imagen; falta montar y probar
- [x] Control desde la interfaz: **seleccionar canción de una lista**, reproducir, pausar, detener
- [x] **Control de volumen** desde la interfaz
- [x] **Retroalimentación sonora** (audios cortos) en los 4 eventos:
  - [x] Inicio del sistema
  - [x] Inicio del modo autónomo
  - [x] Obstáculo detectado
  - [x] Cambio a modo manual
- [x] Definir y probar la política de mezcla/prioridad para que los sonidos de evento no interrumpan indefinidamente la música — el evento pausa la música y la reanuda

---

## 7. Control remoto — servidor web / app móvil — (OBL)

- [x] Levantar el servidor web sobre WiFi/Bluetooth, accesible desde celular o PC — activo en la Raspberry Pi 4, puerto 8080: `docs/evidencias/ejecucion-target.md`
- [x] **Pantalla de login** con al menos un usuario registrado y un protocolo de seguridad mínimo — SHA-256 + sesiones
- [x] Conmutación **modo autónomo ↔ modo manual**
- [x] En modo manual, los controles direccionales comandan directamente los motores
- [x] **Panel de control** que muestre y/o provea:
  - [x] Indicador del modo activo (autónomo/manual)
  - [x] Controles direccionales (modo manual)
  - [x] Lecturas de los sensores de proximidad **en tiempo real** — radar semicircular, velocidad del MPU y tiempo de choque
  - [x] Control completo de audio (lista, reproducir/pausar/detener, volumen)
  - [x] Estado de los LEDs
  - [x] Visualización del mapa de recorrido en tiempo real
- [x] Bloquear los controles manuales mientras el robot está en modo autónomo (y viceversa)

### 7.1 Mapa de recorrido — (OBL)
- [x] Construir un mapa incremental a partir de los **sensores de proximidad + la odometría** — cada lectura del radar con la pose al medir
- [x] Representarlo como **grilla 2D** con 3 estados por celda: visitada / obstáculo detectado / desconocida — celdas de **30 cm**
- [x] Transmitir el mapa al cliente y **actualizarlo en tiempo real** conforme el robot avanza
- [x] Renderizar el mapa en la interfaz web/móvil

### 7.2 Ejecución automática — (OBL)
- [x] Crear la unidad **systemd propia** (`.service`) para la aplicación del servidor
- [x] Arranque automático al energizar el sistema — `WantedBy=multi-user.target`, habilitado desde la receta
- [x] `Restart=on-failure` configurado y probado — verificado con systemd + simulador (`docs/evidencias/systemd-reinicio.md`)
- [x] **Sin interfaz gráfica local** en el sistema embebido
- [x] Habilitar el servicio desde la receta Yocto (no manualmente en el target)

---

## 8. Eficiencia de recursos — (OBL) (EVID)

- [x] Medir el **tamaño del sistema de archivos raíz (rootfs)** — **129 MB** sobre la imagen construida
- [~] Medir el **tiempo de arranque** desde el reset hasta que el servicio de control queda operativo — 17 s medidos el 17 de setiembre; falta repetirlo sobre la imagen final
- [ ] Medir el **uso de memoria RAM** en operación normal
- [ ] Medir el **uso de CPU** en operación normal
- [ ] Escenario de medición: navegación autónoma + audio + servidor web **simultáneos**
- [ ] Justificar cualquier desviación del presupuesto de referencia:
  - [x] rootfs ≤ **200 MB** — 129 MB, dentro del presupuesto
  - [ ] tiempo de arranque ≤ **15 s**
- [x] Documentar las herramientas y el método de medición usados en cada caso (`systemd-analyze`, `du`, `free`, `top`/`htop`, `perf`, lectura directa de `/proc`) — `docs/metricas.md`
- [ ] Incluir la tabla de métricas final en el README

---

## 9. Requerimientos opcionales — (OPC)

- [x] Detección de desnivel / caída con sensores IR orientados hacia abajo + detención preventiva del robot (software; falta montar los sensores, ver `docs/opcionales.md`)
- [x] Notificación de fin de ciclo de limpieza (audio + mensaje en la interfaz), con tiempo o área configurable
- [x] Playlist persistente, almacenada en disco y editable desde la interfaz web

---

## 10. Documentación de atributos profesionales — 10%

### 10.1 Documento de Diseño (DI) — 5%
- [x] **DI1** — Identificación de necesidades y requerimientos del problema complejo de ingeniería, considerando aspectos técnicos, salud y seguridad pública, costos, impacto ambiental y recursos disponibles
- [x] **DI2** — Valoración de alternativas de solución que cumplan las necesidades, considerando múltiples factores (técnicos, económicos, ambientales, sociales)
- [x] **DI3** — Diseño creativo de la alternativa seleccionada, considerando todos los aspectos mencionados
- [~] **DI4** — Validación del diseño final de acuerdo con los requerimientos y las consideraciones de seguridad, costo e impacto — falta la RAM y la CPU en la tabla de eficiencia

### 10.2 Documento de Aprendizaje Continuo (AC) — 5%
- [x] **AC1** — Identificación de necesidades de aprendizaje (conocimientos, habilidades, destrezas o actitudes) en el contexto del proyecto y del cambio tecnológico
- [x] **AC2** — Identificación de tecnologías nuevas y emergentes que contribuyeron con el aprendizaje durante el desarrollo
- [x] **AC3** — Implementación de acciones o estrategias concretas (uso de nuevas tecnologías, organización del tiempo, búsqueda bibliográfica) para solventar las necesidades de aprendizaje
- [x] **AC4** — Evaluación crítica de la eficacia de las estrategias implementadas

---

## 11. README y documentación — 10%

- [x] Instrucciones de **instalación**
- [x] Instrucciones de **compilación** con la toolchain
- [x] Instrucciones de **generación de la imagen Yocto**, incluyendo la receta `.bb` propia y cómo agregar la capa `meta-robot/`
- [x] **Configuración y uso** del sistema (login, modos, audio, mapa)
- [x] **Diagrama de arquitectura de hardware**
- [x] **Diagrama de arquitectura de software**
- [x] **Documentación de la API** de la biblioteca dinámica
- [x] **Evidencias** de la compilación cruzada automatizada (fragmento del log de Yocto + ejecución en el target)
- [~] **Reporte de métricas** de eficiencia de recursos y herramientas utilizadas para medirlas — faltan la RAM y la CPU
- [~] Resultados más relevantes del proyecto con **evidencias de ejecución** (fotos, videos, capturas) — faltan las fotos y el video del robot
- [x] Lista de todo paquete agregado sobre la imagen base + **justificación de cada uno** — `docs/paquetes.md`

---

## 12. Presentación funcional — 70%

- [ ] Ensayo completo de la demo según la rúbrica correspondiente
- [ ] Demostrar navegación autónoma con evasión de obstáculos
- [ ] Demostrar el cambio a modo manual y el control direccional desde la interfaz
- [ ] Demostrar reproducción MP3 + control de volumen concurrente con la navegación
- [ ] Demostrar los 4 sonidos de retroalimentación
- [ ] Demostrar los 4 LEDs indicadores
- [ ] Demostrar el mapa actualizándose en tiempo real
- [ ] Demostrar el arranque automático (reset del sistema en vivo)
- [ ] Estética del modelo físico presentable (rubro evaluado)
- [ ] Plan B ante fallos (batería de repuesto, superficie de prueba controlada, video de respaldo)

---

## 13. Checklist final pre-entrega (6 de octubre de 2026)

- [ ] `bitbake <imagen>` reproduce la imagen desde cero, sin pasos manuales — **verificado en una máquina limpia**
- [ ] Todos los requerimientos obligatorios implementados y probados en el target
- [x] `meta-robot/`, `log.do_compile` y las capturas del target están commiteados
- [ ] README completo con diagramas, API y métricas
- [ ] Documentos DI y AC finalizados y subidos al repositorio
- [ ] Historial Git limpio, con Conventional Commits, ramas e issues cerrados
- [ ] Batería cargada y robot funcionando el día de la presentación

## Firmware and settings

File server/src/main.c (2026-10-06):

/*
 * Proyecto I - Robot Aspiradora Autonomo
 * CE-1113 Sistemas Empotrados, Instituto Tecnologico de Costa Rica
 *
 * Archivo derivado del proyecto Proyecto1_RobotYocto---Sistemas-Empotrados,
 * MIT License - Copyright (c) 2026 Javier Tenorio Cervantes. Ver NOTICE.md.
 */

#include <microhttpd.h>
#include <stdio.h>
#include <stdlib.h>
#include <string.h>
#include <signal.h>
#include <unistd.h>
#include <pthread.h>
#include <sys/stat.h>
#include <fcntl.h>
#include <math.h>
#include <time.h>

#include "robot_state.h"
#include "lib_audio.h"
#include "lib_leds.h"
#include "auth.h"
#include "api.h"
#include "lib_robot.h"
#include "lib_motors.h"
#include "lib_odom.h"
#include "lib_radar.h"
#include "lib_caida.h"

/* El estado global guarda una lectura por angulo del radar. */
_Static_assert(RADAR_LECTURAS_MAX >= RADAR_N_ANGULOS,
               "RADAR_LECTURAS_MAX (robot_state.h) no alcanza para el barrido del radar");

// Configuraciones del servidor iniciales
#define SERVER_PORT      8080
#define WWW_ROOT         "./www"
#define MAX_UPLOAD_BYTES (32 * 1024)

// Body del POST
typedef struct {
    char  *data;
    size_t used;
} UploadBuf;

// Serving File
static const char *mime_for(const char *path) {
    const char *d = strrchr(path, '.');
    if (!d)                       return "application/octet-stream";
    if (strcmp(d, ".html") == 0)  return "text/html; charset=utf-8";
    if (strcmp(d, ".css")  == 0)  return "text/css";
    if (strcmp(d, ".js")   == 0)  return "application/javascript";
    if (strcmp(d, ".ico")  == 0)  return "image/x-icon";
    if (strcmp(d, ".png")  == 0)  return "image/png";
    if (strcmp(d, ".svg")  == 0)  return "image/svg+xml";
    return "application/octet-stream";
}

static enum MHD_Result serve_file(struct MHD_Connection *conn,
                                   const char *rel)
{
    char path[512];
    snprintf(path, sizeof(path), "%s%s", WWW_ROOT, rel);

    int fd = open(path, O_RDONLY);
    if (fd < 0) return MHD_NO;

    struct stat st;
    if (fstat(fd, &st) < 0 || !S_ISREG(st.st_mode)) { close(fd); return MHD_NO; }

    struct MHD_Response *r =
        MHD_create_response_from_fd((uint64_t)st.st_size, fd);
    MHD_add_response_header(r, "Content-Type",  mime_for(path));
    MHD_add_response_header(r, "Cache-Control", "no-cache");
    enum MHD_Result ret = MHD_queue_response(conn, MHD_HTTP_OK, r);
    MHD_destroy_response(r);
    return ret;
}

static enum MHD_Result send_redirect(struct MHD_Connection *conn,
                                      const char *to)
{
    struct MHD_Response *r =
        MHD_create_response_from_buffer(0, NULL, MHD_RESPMEM_PERSISTENT);
    MHD_add_response_header(r, "Location", to);
    enum MHD_Result ret = MHD_queue_response(conn, MHD_HTTP_FOUND, r);
    MHD_destroy_response(r);
    return ret;
}

static enum MHD_Result send_404(struct MHD_Connection *conn) {
    const char *b = "{\"error\":\"Not found\"}";
    struct MHD_Response *r =
        MHD_create_response_from_buffer(strlen(b), (void *)b,
                                        MHD_RESPMEM_PERSISTENT);
    MHD_add_response_header(r, "Content-Type", "application/json");
    enum MHD_Result ret = MHD_queue_response(conn, MHD_HTTP_NOT_FOUND, r);
    MHD_destroy_response(r);
    return ret;
}

static enum MHD_Result send_401(struct MHD_Connection *conn) {
    const char *b = "{\"error\":\"Unauthorized\"}";
    struct MHD_Response *r =
        MHD_create_response_from_buffer(strlen(b), (void *)b,
                                        MHD_RESPMEM_PERSISTENT);
    MHD_add_response_header(r, "Content-Type", "application/json");
    enum MHD_Result ret = MHD_queue_response(conn, MHD_HTTP_UNAUTHORIZED, r);
    MHD_destroy_response(r);
    return ret;
}

/* ══════════════════════════════════════════════════════════
   Main request handler / router
══════════════════════════════════════════════════════════ */
static enum MHD_Result handle_request(
    void *cls,
    struct MHD_Connection *conn,
    const char *url,
    const char *method,
    const char *version,
    const char *upload_data,
    size_t     *upload_data_size,
    void      **con_cls)
{
    (void)cls; (void)version;

    // First call para los acumuladores
    if (*con_cls == NULL) {
        UploadBuf *buf = calloc(1, sizeof(UploadBuf));
        if (!buf) return MHD_NO;
        *con_cls = buf;
        return MHD_YES;
    }

    UploadBuf *ub = *con_cls;

    /* Acumular los POST body */
    if (*upload_data_size > 0) {
        size_t need = ub->used + *upload_data_size + 1;
        if (need > MAX_UPLOAD_BYTES) return MHD_NO;
        ub->data = realloc(ub->data, need);
        if (!ub->data) return MHD_NO;
        memcpy(ub->data + ub->used, upload_data, *upload_data_size);
        ub->used             += *upload_data_size;
        ub->data[ub->used]   = '\0';
        *upload_data_size    = 0;
        return MHD_YES;
    }

    /* Todos los body recibidos */
    int is_get  = strcmp(method, "GET")  == 0;
    int is_post = strcmp(method, "POST") == 0;
    const char *body = ub->data ? ub->data : "";

    /* Establecer los CORS de seguridad */
    if (strcmp(method, "OPTIONS") == 0) {
        struct MHD_Response *r =
            MHD_create_response_from_buffer(0, NULL, MHD_RESPMEM_PERSISTENT);
        MHD_add_response_header(r, "Access-Control-Allow-Origin",  "*");
        MHD_add_response_header(r, "Access-Control-Allow-Methods", "GET, POST, OPTIONS");
        MHD_add_response_header(r, "Access-Control-Allow-Headers", "Content-Type");
        enum MHD_Result ret = MHD_queue_response(conn, MHD_HTTP_NO_CONTENT, r);
        MHD_destroy_response(r);
        return ret;
    }

    /* ── Rutas publicas ── */
    if (is_get && (strcmp(url, "/") == 0 || strcmp(url, "/index.html") == 0))
        return serve_file(conn, "/login.html");

    if (is_post && strcmp(url, "/api/login") == 0)
        return api_login(conn, body, ub->used);

    /* ── Autenticacion ── */
    if (!auth_check_request(conn)) {
        if (strncmp(url, "/api/", 5) == 0) return send_401(conn);
        return send_redirect(conn, "/");
    }

    /* ── Rutas de paginas protegidas ── */
    if (is_get && strcmp(url, "/dashboard") == 0)
        return serve_file(conn, "/dashboard.html");

    /* ── Rutas de API protegidas ── */
    if (is_post && strcmp(url, "/api/logout") == 0)
        return api_logout(conn);

    if (is_get  && strcmp(url, "/api/status") == 0)
        return api_status(conn);

    if (is_post && strcmp(url, "/api/mode") == 0)
        return api_set_mode(conn, body, ub->used);

    if (is_post && strcmp(url, "/api/move") == 0)
        return api_move(conn, body, ub->used);

    if (is_get  && strcmp(url, "/api/audio/list") == 0)
        return api_audio_list(conn);

    if (is_post && strcmp(url, "/api/audio/control") == 0)
        return api_audio_control(conn, body, ub->used);

    if (is_post && strcmp(url, "/api/audio/volume") == 0)
        return api_audio_volume(conn, body, ub->used);

    if (is_get  && strcmp(url, "/api/audio/playlist") == 0)
        return api_audio_playlist_get(conn);

    if (is_post && strcmp(url, "/api/audio/playlist") == 0)
        return api_audio_playlist_set(conn, body, ub->used);

    if (is_post && strcmp(url, "/api/ciclo") == 0)
        return api_ciclo(conn, body, ub->used);

    return send_404(conn);
}

static void request_done(void *cls, struct MHD_Connection *conn,
                          void **con_cls,
                          enum MHD_RequestTerminationCode toe)
{
    (void)cls; (void)conn; (void)toe;
    UploadBuf *ub = *con_cls;
    if (ub) { free(ub->data); free(ub); *con_cls = NULL; }
}

/* ══════════════════════════════════════════════════════════
   Hilo de actualizacion
══════════════════════════════════════════════════════════ */
static volatile int g_running = 1;

static void *uptime_thread(void *arg) {
    (void)arg;
    while (g_running) {
        sleep(1);
        RobotState *rs = robot_state_get();
        if (rs) {
            pthread_mutex_lock(&rs->lock);
            rs->uptime_secs++;
            pthread_mutex_unlock(&rs->lock);
        }
    }
    return NULL;
}

/* ══════════════════════════════════════════════════════════
   Hilo watchdog, para volver al modo autonomo una vez
   no hay usuarios logueados en el servidor
══════════════════════════════════════════════════════════ */
#define WATCHDOG_INTERVAL_SECS 7

static void set_auto_mode(const char *reason) {
    RobotState *rs = robot_state_get();
    if (!rs) return;
    pthread_mutex_lock(&rs->lock);
    if (rs->mode != MODE_AUTONOMOUS) {
        rs->mode            = MODE_AUTONOMOUS;
        rs->leds.autonomous = 1;
        rs->leds.manual     = 0;
        pthread_mutex_unlock(&rs->lock);     
        printf("[watchdog] %s → modo AUTONOMO\n", reason);
        lib_audio_notify(NOTIFY_AUTONOMOUS);  
        return;
    }
    pthread_mutex_unlock(&rs->lock);
}

static void *watchdog_thread(void *arg) {
    (void)arg;
    while (g_running) {
        sleep(WATCHDOG_INTERVAL_SECS);
        int sesiones = auth_active_sessions();
        // printf("[watchdog] tick — sesiones activas: %d\n", sesiones);
        if (sesiones == 0)
            set_auto_mode("sin sesiones activas");
    }
    return NULL;
}

/* ══════════════════════════════════════════════════════════
   Mapa de recorrido
══════════════════════════════════════════════════════════ */

/* Cada celda mide MAP_CELDA_CM (30 cm, ver robot_state.h): del orden del
   diametro del robot, asi que "celda visitada" es "el robot paso por aca". */

/* Mas alla de esta distancia un eco no marca obstaculo: de lejos, el cono del
   HC-SR04 ya abarca varias celdas y la posicion del eco es poco precisa. */
#define MAP_ALCANCE_CM 150.0

/* Pasa de cm del mundo (este y norte positivos) a la grilla: el origen queda
   en el centro del mapa y la fila 0 apunta al norte. 0 si cae afuera. */
static int celda_de(double x_cm, double y_cm, int *col, int *fil) {
    *col = MAP_COLS / 2 + (int)lround(x_cm / MAP_CELDA_CM);
    *fil = MAP_ROWS / 2 - (int)lround(y_cm / MAP_CELDA_CM);
    return *col >= 0 && *col < MAP_COLS && *fil >= 0 && *fil < MAP_ROWS;
}

/* Proyecta una lectura del radar sobre la grilla, con la pose que tenia el
   robot al medirla. Se llama con rs->lock tomado. */
static void map_marcar_lectura(RobotState *rs, const RadarLectura *l) {
    /* Sin eco puede no haber nada, o puede ser una pared oblicua que desvio
       el pulso: no se concluye nada. */
    if (l->distancia_cm <= 0.0) return;

    double ox, oy, rumbo;
    radar_rayo(l, &ox, &oy, &rumbo);
    double dx = sin(rumbo * M_PI / 180.0), dy = cos(rumbo * M_PI / 180.0);

    int rc, rf;
    celda_de(l->x_cm, l->y_cm, &rc, &rf);

    /* Las celdas que el rayo cruza antes del eco estan libres. Si alguna
       habia quedado como obstaculo —un eco falso, o algo que se movio— vuelve
       a desconocida. Se deja media celda de margen antes del eco. */
    double libre = fmin(l->distancia_cm, MAP_ALCANCE_CM) - MAP_CELDA_CM / 2.0;
    for (double t = 0.0; t < libre; t += MAP_CELDA_CM / 3.0) {
        int c, f;
        if (!celda_de(ox + t * dx, oy + t * dy, &c, &f)) break;
        if (rs->map.grid[f][c] == CELL_OBSTACLE) rs->map.grid[f][c] = CELL_UNKNOWN;
    }

    if (l->distancia_cm > MAP_ALCANCE_CM) return;

    int oc, of;
    if (!celda_de(ox + l->distancia_cm * dx, oy + l->distancia_cm * dy, &oc, &of))
        return;

    /* Un eco que cae en la celda del propio robot no se marca, o el robot se
       encerraria solo. */
    if (oc == rc && of == rf) return;

    rs->map.grid[of][oc] = CELL_OBSTACLE;
}

/* ══════════════════════════════════════════════════════════
   Estado de los sensores
══════════════════════════════════════════════════════════ */

/* Un obstaculo al frente se detecta por cualquiera de dos vias:
   - distancia: alguna lectura del cono frontal (servo a 60, 90 o 120 grados)
     por debajo de DIST_OBSTACULO_CM;
   - tiempo: el tiempo antes de chocar del radar por debajo de
     TTC_OBSTACULO_S. Es la via que reacciona antes cuanto mas rapido va el
     robot: a 25 cm/s salta a unos 30 cm de la pared.
   La distancia cubre al robot quieto o muy lento, donde no hay tiempo de
   choque que calcular. */
#define DIST_OBSTACULO_CM 20.0
#define TTC_OBSTACULO_S    1.2
#define CONO_FRONTAL_GRADOS 30

/* Una lectura del cono frontal cuenta solo si es reciente y si el robot sigue
   mirando hacia donde miraba al tomarla: tras un giro, "lo que habia al
   frente" es otra cosa. */
#define LECTURA_VIGENTE_S       2.0
#define LECTURA_GIRO_MAX_GRADOS 20.0

static uint32_t g_mapa_seq = 0;   /* ultima lectura del radar ya mapeada */

/* Ultima lectura de los sensores de desnivel (bits CAIDA_IZQ y CAIDA_DER).
   La escribe actualizar_estado(), que corre en el hilo de navegacion. */
static volatile int g_caida = 0;

static double diferencia_rumbo(double a, double b) {
    return fabs(fmod(a - b + 540.0, 360.0) - 180.0);
}

/* Menor distancia vigente en el cono frontal, o -1 si no hay ninguna. */
static double distancia_al_frente(const RadarLectura *l, int n, double rumbo) {
    double d = -1.0;
    for (int i = 0; i < n; i++) {
        if (abs(l[i].angulo - RADAR_FRENTE) > CONO_FRONTAL_GRADOS) continue;
        if (l[i].seq == 0 || l[i].distancia_cm <= 0.0)             continue;
        if (l[i].edad_s > LECTURA_VIGENTE_S)                       continue;
        if (diferencia_rumbo(l[i].rumbo_grados, rumbo) > LECTURA_GIRO_MAX_GRADOS) continue;
        if (d < 0.0 || l[i].distancia_cm < d) d = l[i].distancia_cm;
    }
    return d;
}

static double lectura_en(const RadarLectura *l, int n, int angulo) {
    for (int i = 0; i < n; i++)
        if (l[i].angulo == angulo) return l[i].distancia_cm;
    return -1.0;
}

/* Lee el radar y la odometria y lo vuelca todo al estado global: sensores,
   velocidad, tiempo de choque, LED de obstaculo y mapa. Devuelve 1 si hay un
   obstaculo al frente.

   No mueve motores ni suena nada: se llama tambien en medio de las maniobras,
   para que el panel y el mapa sigan vivos mientras el robot retrocede o gira. */
static int actualizar_estado(RobotState *rs) {
    RadarLectura l[RADAR_N_ANGULOS];
    int n = radar_lecturas(l, RADAR_N_ANGULOS);

    RadarChoque choque;
    radar_estado_choque(&choque);

    double x_cm, y_cm, rumbo;
    odom_get(&x_cm, &y_cm, &rumbo);

    double d_frente  = distancia_al_frente(l, n, rumbo);
    int    obstaculo = (d_frente > 0.0 && d_frente < DIST_OBSTACULO_CM) ||
                       (choque.ttc_s >= 0.0 && choque.ttc_s < TTC_OBSTACULO_S);

    /* Se lee en cada actualizacion, tambien en medio de las maniobras: a
       25 cm/s el robot avanza menos de 3 cm entre dos lecturas. */
    int caida = caida_leer();
    g_caida = caida;

    pthread_mutex_lock(&rs->lock);

    rs->sensors.front_cm = (float)lectura_en(l, n, RADAR_FRENTE);
    rs->sensors.left_cm  = (float)lectura_en(l, n, 180);
    rs->sensors.right_cm = (float)lectura_en(l, n, 0);

    rs->radar.angulo_servo = radar_angulo_actual();
    rs->radar.n = n < RADAR_LECTURAS_MAX ? n : RADAR_LECTURAS_MAX;
    for (int i = 0; i < rs->radar.n; i++) {
        rs->radar.lecturas[i].angulo       = l[i].angulo;
        rs->radar.lecturas[i].distancia_cm = (float)l[i].distancia_cm;
        rs->radar.lecturas[i].edad_s       = (float)l[i].edad_s;
    }

    rs->movimiento.velocidad_cm_s = (float)odom_velocidad_cm_s();
    rs->movimiento.ttc_s          = (float)choque.ttc_s;
    rs->movimiento.imu            = odom_usa_imu();

    rs->caida.izq = (caida & CAIDA_IZQ) != 0;
    rs->caida.der = (caida & CAIDA_DER) != 0;

    /* El LED de alerta se enciende igual ante un obstaculo o un desnivel. */
    int alerta = obstaculo || caida;
    int cambio_led = rs->leds.obstacle != alerta;
    rs->leds.obstacle = alerta;

    /* Cada lectura nueva del radar, una sola vez. */
    uint32_t mayor = g_mapa_seq;
    for (int i = 0; i < n; i++) {
        if (l[i].seq <= g_mapa_seq) continue;
        map_marcar_lectura(rs, &l[i]);
        if (l[i].seq > mayor) mayor = l[i].seq;
    }
    g_mapa_seq = mayor;

    /* La celda del robot, al final: el robot esta ahi, asi que no puede ser
       un obstaculo aunque un eco lo haya marcado antes. */
    int c, f;
    if (celda_de(x_cm, y_cm, &c, &f)) {
        rs->map.robot_x = c;
        rs->map.robot_y = f;
        rs->map.grid[f][c] = CELL_VISITED;
    }
    rs->map.robot_heading = ((int)lround(rumbo)) % 360;

    pthread_mutex_unlock(&rs->lock);

    if (cambio_led) lib_leds_set(LED_OBSTACLE, alerta);
    return obstaculo;
}

/* ══════════════════════════════════════════════════════════
   Maniobras
══════════════════════════════════════════════════════════ */

#define VEL_CRUCERO    210
#define VEL_GIRO       200
#define VEL_RETROCESO  180
#define RETROCESO_MS   500
#define PASO_MS         50

/* Con menos espacio que esto en todas las direcciones, se da media vuelta. */
#define ESPACIO_LIBRE_CM 40.0

/* Lecturas parecidas a la mejor, dentro de este margen, compiten al azar. */
#define MARGEN_EMPATE_CM 25.0

/* Tope de tiempo para un giro: a VEL_GIRO el robot gira unos 180 grados/s;
   el tope deja margen para piso resbaloso o bateria baja. */
#define GIRO_MS_POR_GRADO 20
#define GIRO_TOLERANCIA    5.0

static OperationMode modo_actual(RobotState *rs) {
    pthread_mutex_lock(&rs->lock);
    OperationMode m = rs->mode;
    pthread_mutex_unlock(&rs->lock);
    return m;
}

/* Espera troceada que mantiene vivos el panel y el mapa durante una maniobra.
   Devuelve 0 si hay que abortarla: el servidor se apaga o el usuario paso a
   modo manual. La odometria ya no depende de esto: corre en su propio hilo
   dentro de librobot. */
static int esperar_ms(RobotState *rs, int ms) {
    for (int t = 0; t < ms; t += PASO_MS) {
        usleep(PASO_MS * 1000);
        actualizar_estado(rs);
        if (!g_running || modo_actual(rs) != MODE_AUTONOMOUS) return 0;
    }
    return 1;
}
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
int main(void) {
    /* Bajo systemd la salida va a un pipe, no a una terminal, y printf la
       acumularia en bloques de 4 KB: journalctl mostraria los eventos tarde
       o nunca si el proceso muere. Linea a linea, como en la consola. */
    setvbuf(stdout, NULL, _IOLBF, 0);

    printf("╔════════════════════════════════════╗\n");
    printf("║  Servidor Vaccum Robot             ║\n");
    printf("╚════════════════════════════════════╝\n\n");

    if (robot_state_init() < 0)  { fprintf(stderr, "[main] estado inicial fallo\n");}

    /* La eleccion de rumbo tras un obstaculo desempata al azar. */
    srand((unsigned)time(NULL));

    /* --- INICIALIZAR EL HARDWARE ---
       robot_init() abre la sesion con pigpiod, deja listos motores y LEDs,
       calibra el MPU-6050 y arranca la odometria y el barrido del radar. El
       servidor no toca GPIO: todo pasa por librobot. */
    if (robot_init() < 0) {
        fprintf(stderr, "[main] hardware init failed (requiere pigpiod corriendo)\n");
        robot_state_destroy();
        return 1;
    }

    if (lib_audio_init(NULL) < 0)  { fprintf(stderr, "[main] audio init failed\n");}
    if (auth_init()        < 0)  { fprintf(stderr, "[main] autorizacion inicial fallo\n");}

    // Iniciar en modo autonomo. Se fija antes de abrir el puerto para que un
    // cambio de modo pedido desde el panel no quede pisado despues.
    {
        RobotState *rs = robot_state_get();
        if (rs) {
            pthread_mutex_lock(&rs->lock);
            rs->mode = MODE_AUTONOMOUS;
            pthread_mutex_unlock(&rs->lock);
        }
    }

    signal(SIGINT,  on_signal);
    signal(SIGTERM, on_signal);

    /* El servidor HTTP se abre antes de los sonidos de inicio: cada
       lib_audio_notify() bloquea hasta que termina el MP3 (unos 6 s entre los
       dos), y el panel debe ser alcanzable cuanto antes. MHD atiende en sus
       propios hilos, asi que no espera al main. */
    g_daemon = MHD_start_daemon(
        MHD_USE_THREAD_PER_CONNECTION | MHD_USE_INTERNAL_POLLING_THREAD,
        SERVER_PORT,
        NULL, NULL,
        handle_request, NULL,
        MHD_OPTION_NOTIFY_COMPLETED, request_done, NULL,
        MHD_OPTION_CONNECTION_TIMEOUT, (unsigned int)30,
        MHD_OPTION_END
    );

    if (!g_daemon) {
        fprintf(stderr, "[main] fallo al iniciar el daemon en puerto %d\n", SERVER_PORT);
        auth_destroy();
        lib_audio_destroy();
        robot_shutdown();
        robot_state_destroy();
        lib_leds_destroy();
        return 1;
    }

    printf("[server] Servidor escuchando en puerto %d\n\n", SERVER_PORT);
    printf("  Dev:               http://localhost:%d\n", SERVER_PORT);
    printf("  Red local:         http://<hostname -I>:%d\n",   SERVER_PORT);

    // Notificacion de encendido
    lib_audio_notify(NOTIFY_STARTUP);

    printf("[main] Modo inicial: AUTONOMO\n");
    lib_audio_notify(NOTIFY_AUTONOMOUS);

    lib_leds_sync_from_state();

    // Inicializar Threads
    pthread_t tid_uptime, tid_watchdog;
    pthread_create(&tid_uptime,   NULL, uptime_thread,   NULL);
    pthread_create(&tid_watchdog, NULL, watchdog_thread, NULL);

    // --- INICIAR HILO DE NAVEGACIÓN AUTÓNOMA ---
    pthread_t auto_tid;
    pthread_create(&auto_tid, NULL, autonomous_thread, NULL);

    while (g_running) sleep(1);

    // --- SECUENCIA DE APAGADO ---
    g_running = 0;
    pthread_join(tid_uptime,   NULL);
    pthread_join(tid_watchdog, NULL);
    pthread_join(auto_tid,     NULL); // Esperar a que el hilo autónomo termine
    
    auth_destroy();
    lib_audio_destroy();
    robot_shutdown(); // Detener motores, apagar LEDs y cerrar la sesion de pigpiod
    robot_state_destroy();
    lib_leds_destroy(); // Apagar LEDs físicos
    
    printf("[server] Close.\n");
    return 0;
}

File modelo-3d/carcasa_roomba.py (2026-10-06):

# -*- coding: utf-8 -*-
"""
Carcasa tipo Roomba en dos piezas (inferior + superior) y sus tres ruedas, paramétrica, para impresión 3D.
Versión simple y liviana: solo los espacios de cada componente, sin tornillos.
  - Las dos piezas se unen a presión con 4 pestañas de clic.
  - Dos ruedas motrices que entran a presión en el eje en D del motor.
  - Tercera rueda de apoyo: bola de 16 mm en un asiento de la pieza inferior, sujeta por un aro a presión.
Requiere CadQuery (pip install cadquery).  Uso:  python carcasa_roomba.py

Ejes: X = izquierda/derecha, Y = atrás(-)/frente(+), Z = arriba.  Z = 0 es la cara de abajo del piso.
Todas las medidas en mm.
"""
import os
import sys
from math import pi, sqrt
import cadquery as cq

OUT = os.path.dirname(os.path.abspath(__file__))

# ===================== PARÁMETROS =====================
# --- carcasa (espesores bajos para que pese poco) ---
D = 215.0            # diámetro exterior (la cama de la impresora mide 249 x 219 mm)
R = D / 2
WALL = 1.6           # espesor de pared de la pieza superior
FLOOR = 2.0          # espesor del piso
LID = 1.6            # espesor de la tapa
H = 45.0             # altura total de la carcasa (sin contar la separación al suelo)
FIT = 0.2            # holgura entre las dos piezas
BW_T = 1.6           # espesor de la pared interna de la pieza inferior
BW_TOP = 18.0        # hasta qué altura sube esa pared

# --- cierre a presión (clic) ---
TAB_ANGLES = (45, 135, 225, 315)   # dónde van las 4 pestañas
TAB_L, TAB_H = 20.0, 6.0           # largo y alto de cada pestaña flexible
TAB_Z = 11.0                       # altura del centro de la pestaña
BUMP_OUT = 1.0                     # cuánto sobresale el botón de clic
KEY_ANGLE = 90                     # guía al frente: la tapa solo entra en una posición
NOTCH_ANGLES = (0, 180)            # muescas para los dedos (para abrir)

# --- motores: micro motorreductor AD12672. No llevan soporte: se apoyan sobre el piso, junto a la ranura ---
MOTOR_L, MOTOR_W, MOTOR_H = 26.0, 12.0, 10.0   # cuerpo: largo (a lo largo del eje), ancho, alto
SHAFT_D, SHAFT_FLAT, SHAFT_L = 3.0, 2.5, 10.0  # eje en D: diámetro, medida sobre el plano, largo
MOTOR_X = 85.5       # posición en X (+/-) de la cara del motor de donde sale el eje (referencia)
WHEEL_Y = 12.0       # eje de las ruedas en Y (adelantado: la rueda de apoyo va atrás)

# --- ruedas motrices (impresas) ---
WHEEL_D = 30.0       # diámetro
WHEEL_W = 8.0        # ancho de la banda de rodadura
HUB_D = 9.0          # diámetro del cubo
HUB_L = 10.0         # largo del cubo (igual al eje)
BORE_FIT = 0.1       # holgura del agujero en D (entra a presión)
WHEEL_GAP = 3.0      # holgura adelante y atrás de la rueda en la ranura del piso

# --- rueda de apoyo: bola de 16 mm (canica o impresa) ---
BALL_D = 16.0
CASTER_Y = -84.0
RING_H = 4.0         # alto del aro que sujeta la bola por debajo
RING_R = 18.0        # radio exterior del aro
PIN_R_POS = 14.5     # distancia de los dos pines del aro al centro
PIN_D = 4.1          # diámetro de los pines (partidos, entran a presión)
PIN_H = 6.0

# --- ventilador de succión 30 x 30 x 12 mm (AD32862) ---
FAN = 30.0
FAN_T = 12.0
FAN_Y = 84.5
FAN_INTAKE_D = 28.0
FAN_FRAME_H = 8.0

# --- variante "succión" de la pieza inferior: campana sobre una boca ancha + boquilla cerca del suelo ---
HOOD_HALF_W = 36.0             # medio ancho interior de la campana en el piso
HOOD_Y0, HOOD_Y1 = 67.0, 96.0  # de dónde a dónde va la campana en el piso (interior)
HOOD_H = 22.0                  # altura de la campana; el ventilador va encima
MOUTH_DEPTH = 12.0             # fondo de la boca de succión (ranura en el piso)
LIP_H = 4.0                    # reborde detrás de la boca, para que el polvo no se devuelva
NOZZLE_GAP = 2.0               # distancia de la boquilla al suelo
NOZZLE_PIN_X = 43.0            # posición de los dos pines de la boquilla
RPI_SHIFT_SUCCION = -4.0       # en esta variante la Raspberry va 4 mm más atrás, para dejar sitio a los USB

# --- Raspberry Pi 4 (85 x 56 mm, agujeros de 2.7 mm en rectángulo 58 x 49) ---
# Va a la derecha, a lo largo: SD hacia atrás, USB/Ethernet hacia el frente, GPIO hacia la placa perforada
RPI_X_PORTS = 59.0   # borde de USB-C/HDMI (hacia la derecha, +X)
RPI_Y_SD = -48.0     # borde de la tarjeta SD (hacia atrás)
RPI_STANDOFF_H = 6.0

# --- placa perforada 76 x 125 mm ---
# Va a la izquierda, a lo largo. Queda elevada: el motor izquierdo pasa por debajo
PB_X, PB_Y, PB_T = 76.0, 125.0, 1.6
PB_CX, PB_CY = -38.7, 0.0   # centro de la placa
PB_LEDGE_H = 11.0    # altura a la que queda apoyada la placa sobre el piso
PB_RIM = 2.0         # cuánto sobresale cada esquina de apoyo por fuera de la placa

# --- botón de encendido (pulsador de panel) ---
BUTTON_D = 16.2      # diámetro del agujero (botón de 16 mm)
BUTTON_POS = (-45.0, 80.0)

# ===================== derivados =====================
AXLE_Z = FLOOR + MOTOR_H / 2                 # eje del motor, con el motor apoyado sobre el piso
CLEAR = WHEEL_D / 2 - AXLE_Z                 # separación entre el piso de la carcasa y el suelo
BALL_ZC = BALL_D / 2 - CLEAR                 # altura del centro de la bola
R_IN = R - WALL                              # radio interior de la pieza superior
R_BW = R_IN - FIT                            # radio exterior de la pared de la pieza inferior
MOUTH_Y1 = HOOD_Y1 - 1.0                     # la boca queda al frente de la campana
MOUTH_Y0 = MOUTH_Y1 - MOUTH_DEPTH
MOUTH_YC = (MOUTH_Y0 + MOUTH_Y1) / 2


def rpi_y_sd(succion):
    return RPI_Y_SD + (RPI_SHIFT_SUCCION if succion else 0.0)


def rpi_holes(succion):
    return [(RPI_X_PORTS - v, rpi_y_sd(succion) + u) for u in (3.5, 61.5) for v in (3.5, 52.5)]
BUMP_R = 2.4                                 # radio de la base del botón de clic
BUMP_Y = TAB_L / 2 - 4.0                     # posición del botón a lo largo de la pestaña
CONE_K = BALL_D / 2 * sqrt(2)                # cono a 45° tangente a la bola: r = CONE_K - (z - BALL_ZC)
SLOT_X0, SLOT_X1 = MOTOR_X + 1.0, MOTOR_X + SHAFT_L + 2.0   # ranura de cada rueda motriz


def box(x0, x1, y0, y1, z0, z1):
    return cq.Workplane("XY").box(x1 - x0, y1 - y0, z1 - z0, centered=False).translate((x0, y0, z0))


def cyl(x, y, z0, z1, r):
    return cq.Workplane("XY").circle(r).extrude(z1 - z0).translate((x, y, z0))


def rot(obj, angle):
    """Gira alrededor del eje Z una forma construida sobre el eje +X."""
    return obj.rotate((0, 0, 0), (0, 0, 1), angle)


def revolucion(puntos):
    """Sólido de revolución alrededor del eje Z a partir de un perfil (r, z)."""
    return cq.Workplane("XZ").polyline(puntos).close().revolve(360, (0, 0, 0), (0, 1, 0))
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

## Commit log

2026-09-07 chore: define la estructura de directorios y el .gitignore del proyecto
    Establece el arbol de carpetas acordado para el proyecto (lib/, server/,
    meta-robot/, audio/, docs/) con un README propio por directorio que explica
    su responsabilidad, y agrega el README principal del repositorio.
    El .gitignore excluye los artefactos de Yocto (build/, tmp/, sstate-cache/,
    downloads/), los artefactos de compilacion C/CMake (*.o, *.so, CMakeFiles/),
    la biblioteca musical y el archivo de credenciales de WiFi, de modo que solo
    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
2026-09-07 docs: adopta Conventional Commits, GitHub Flow y convenciones de codigo
    Documenta el flujo de trabajo que se evalua en el rubro de gestion de
    repositorio: modelo de ramas main/develop/feature-*, proteccion de main
    mediante Pull Request, formato de mensaje de commit con sus tipos y ambitos,
    y la vinculacion explicita de cada commit y PR con su issue.
    Incluye ademas las convenciones de codigo acordadas para C, recetas BitBake
    e interfaz web, y el NOTICE.md con la atribucion del proyecto de referencia
    bajo licencia MIT del que se derivan parte de las recetas.
    Refs #1
    Refs #2
2026-09-07 chore: agrega la licencia MIT del proyecto
    Se adopta MIT por compatibilidad con el codigo de terceros incorporado, que
    tambien se distribuye bajo esa licencia (ver NOTICE.md).
    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
2026-09-07 docs(yocto): documenta el entorno de build y versiona local.conf.sample
    Define scarthgap como rama comun de poky, meta-raspberrypi y meta-openembedded,
    y documenta el procedimiento completo: dependencias del host, registro de capas,
    configuracion, construccion de la imagen, grabado de la microSD y verificacion
    del rootfs antes de flashear.
    local.conf no se versiona porque contiene rutas absolutas de cada host, asi que
    se agrega meta-robot/conf/local.conf.sample con el bloque especifico del
    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
2026-09-07 feat(yocto): crea la capa meta-robot con su layer.conf y configuracion del BSP
    Estructura la capa propia del proyecto, que es evidencia entregable segun el
    enunciado. layer.conf declara prioridad 10 para que sus bbappends ganen sobre
    los de meta-raspberrypi, fija LAYERSERIES_COMPAT en scarthgap y declara
    LAYERDEPENDS explicitos para que bitbake falle con un mensaje claro si falta
    alguna capa en lugar de un 'Nothing PROVIDES' tardio.
    Incluye la configuracion de plataforma que la imagen necesita:
    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
    [wifi.cfg]
2026-09-07 feat(yocto): agrega las recetas librobot, robot-server y pigpio
    Recetas BitBake propias que integran la biblioteca dinamica y el servidor web
    en la imagen, con compilacion cruzada completa a traves de la toolchain de
    Yocto (inherit cmake). Con esto la imagen se reproduce con un solo
    'bitbake robot-image', sin pasos manuales en el target.
    Las fuentes se ubican en lib/ y server/ en la raiz del repositorio, no dentro
    de la capa: asi existe una sola copia del codigo, que se compila igual desde el
    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
2026-09-07 feat(yocto): agrega robot-image y justifica cada paquete de la imagen
    La imagen parte de core-image-minimal, el punto de partida mas pequeno de poky,
    en vez de core-image-base o full-cmdline, para obligar a declarar
    explicitamente todo lo demas y no arrastrar utilidades que el robot no usa.
    Se excluye la interfaz grafica con IMAGE_FEATURES:remove para que ninguna
    dependencia la reintroduzca, y se instalan solo los cinco modulos de kernel
    que hacen falta (WiFi Broadcom y audio) en lugar del paquete kernel-modules
    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
2026-09-07 feat(yocto): habilita el arranque automatico del servidor con systemd
    Agrega las unidades robot-server.service y pigpiod.service, y las instala y
    habilita desde las propias recetas con SYSTEMD_AUTO_ENABLE, no con un
    systemctl enable en el target: el enunciado exige que la imagen se reproduzca
    desde cero sin pasos manuales posteriores.
    robot-server declara Requires=pigpiod.service en vez de Wants porque librobot
    habla con el demonio por socket y sin el toda operacion de GPIO falla; asi
    systemd lo arranca primero y detiene el servidor si pigpiod se cae.
    Restart=on-failure con RestartSec=5 cubre el requerimiento de recuperacion
    ante fallos, y StartLimitBurst corta el ciclo de reinicios si el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
2026-09-07 docs(yocto): documenta el Toolchain-SDK para desarrollo cruzado ARM
    Procedimiento de generacion, instalacion y uso del SDK, y como verificar que
    la compilacion realmente fue cruzada.
    El SDK se genera desde robot-image y no desde core-image-minimal para que
    traiga los headers y bibliotecas de desarrollo que el software del robot
    necesita: libmicrohttpd, mpg123, alsa-lib y pigpio.
    Se documentan los dos caminos de compilacion cruzada que deben funcionar -el
    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
2026-09-07 docs: actualiza el estado del proyecto y agrega la guia rapida de build
    Marca en TODO.md lo completado en el rubro de gestion de repositorio y en el
    de Yocto, distinguiendo lo que quedo configurado y documentado de lo que sigue
    pendiente por requerir el kit de hardware o un host de build.
    Agrega al README el indice de la documentacion tecnica y una guia rapida que
    lleva de un host limpio a 'bitbake robot-image' en cinco pasos.
    Refs #7
    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
2026-09-07 docs(hw): especifica el hardware, la seguridad electrica y el pinout
    Documentacion de diseno del hardware, para que el montaje se haga contra una
    especificacion verificada y no sobre la marcha. Cada documento cierra con su
    procedimiento de verificacion con multimetro.
    Dos hallazgos que afectan al software y hay que atender antes de energizar:
    1. El PC817 en emisor comun invierte la senal. Con el codigo actual el sentido
    de giro quedaria al reves y, peor, motores_detener() escribe ciclo 0, que
    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
2026-09-08 fix(yocto): corrige el limite de reintentos y la reproducibilidad del build
    Tres defectos encontrados al validar el trabajo anterior.
    1. StartLimitBurst y StartLimitIntervalSec estaban en la seccion [Service] de
    robot-server.service. Desde systemd 229 el limitador de arranques es
    propiedad de la unidad: puesto en [Service] systemd lo ignora en silencio,
    asi que el limite de cinco reintentos que documentamos no existia. Se pasan
    a [Unit]. Detectado con systemd-analyze verify, que reporta
    'Unknown key StartLimitIntervalSec in section [Service], ignoring'. Ambas
    unidades pasan ahora la verificacion sin advertencias.
    2. wifi-config.bb tomaba en SRC_URI un archivo que esta en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
2026-09-08 fix(yocto): quita el comentario en linea de asignacion de local.conf.sample
    El parser de configuracion de bitbake no acepta un comentario al final de una
    linea de asignacion, solo en lineas propias. La linea de ENABLE_UART abortaba
    el parseo con 'ParseError: unparsed line' apenas se anexaba el archivo a
    build/conf/local.conf, o sea que el sample no servia tal cual.
    Detectado al ejecutar bitbake -p robot-image en un host real. Con la
    correccion, las 2851 recetas del arbol parsean sin errores.
    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
2026-09-08 docs(yocto): documenta la regulacion por presion para hosts con poca RAM
    El build de la imagen colgo la maquina de desarrollo al 67 por ciento: 4
    nucleos y 7 GB de RAM con BB_NUMBER_THREADS en 3 agotaron los 4 GB de swap
    cuando coincidieron el do_fetch del kernel de la RPi, el do_compile de binutils
    y un do_configure. No hubo ningun error de receta; bitbake simplemente dejo de
    recibir eventos y perdio contacto con su servidor.
    La leccion es que el limite real es la RAM y no el disco, y que acotar los
    hilos solo acota el caso promedio. BB_PRESSURE_MAX_MEMORY y BB_PRESSURE_MAX_IO
    acotan el pico: bitbake deja de lanzar tareas nuevas mientras la presion del
    kernel supere el umbral. Eso es lo qu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
2026-09-08 fix(yocto): corrige la ruta de LIC_FILES_CHKSUM en robot-server
    do_populate_lic fallaba con 'LIC_FILES_CHKSUM points to an invalid file'.
    La ruta de LIC_FILES_CHKSUM se resuelve relativa a S, y en esta receta S es
    ${WORKDIR}/src porque el CMakeLists del servidor vive en src/. El LICENSE que
    trae el SRC_URI se desempaqueta en ${WORKDIR}, no en ${WORKDIR}/src, asi que
    la ruta relativa apuntaba a un archivo inexistente. Se usa la ruta absoluta.
    librobot no tenia el problema porque alli S es ${WORKDIR}, que es justo donde
    cae el LICENSE; por eso paso su do_populate_lic sin novedad y este no.
    Detectado en el build real de la imagen.
    Refs #10
2026-09-08 docs(yocto): documenta el fallo de do_fetch del kernel con git 2.4x
    El do_fetch de linux-raspberrypi aborta con 'Unable to find revision ... in
    branch rpi-6.6.y even from upstream', pero el mensaje es enganoso: la revision
    esta en el mirror local y es alcanzable desde la rama.
    BitBake comprueba la alcanzabilidad con 'git branch --contains <rev> --list
    <rama> 2> /dev/null | wc -l'. En el mirror bare deja HEAD en
    refs/heads/.invalid a proposito, para evitar checkouts accidentales, y git 2.4x
    aborta git branch cuando HEAD no resuelve. Como BitBake descarta el stderr, el
    'fatal: failed to resolve HEAD as a valid ref' queda oculto y wc -l devuelve 0,
    que BitBake lee como revision inexistente.
    E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
2026-09-08 docs(evid): guarda la evidencia de compilacion cruzada de un build real
    Evidencia entregable de los issues 8 y 10, extraida de un build real de
    bitbake robot-image sobre poky scarthgap.
    Los fragmentos de log.do_compile de librobot, robot-server y pigpio muestran
    aarch64-poky-linux-gcc con -mcpu=cortex-a72 invocado desde el sysroot nativo:
    el gcc del host no interviene en ningun momento.
    binarios-target.md registra que librobot.so.1.0.0 y robot-server son ELF ARM
    aarch64, que el servidor declara NEEDED librobot.so.1 -lo que demuestra a nivel
    de enlazado el requisito de que todo acceso al hardware pase por la biblioteca
    propia-, que el versionado del .so y su separacion en paquetes es la esp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
2026-09-09 perf(yocto): recorta el build para hosts que se congelan
    Documenta en local.conf.sample los tres ajustes con los que el build
    sobrevive en el host de 4 nucleos y 7 GB: sin SPDX, sin el gcc del target
    y con las tareas en la prioridad mas baja de CPU y E/S.
    El gcc del target entraba al grafo solo por los RDEPENDS de elfutils-ptest
    y python3-ptest, paquetes de pruebas que ni siquiera se empaquetan. Es la
    tarea mas pesada del build y es donde la maquina se congelo tres veces.
    Total de tareas de la imagen: 6014 -> 4950. Con esta configuracion el
    build completo termino sin errores y sin colgar la maquina.
2026-09-09 style(yocto): restaura la linea en blanco que se perdio al resolver el merge
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2026-09-09 test(sim): simulador de hardware para probar librobot sin la Raspberry
    Corre la biblioteca de control completa en la laptop sustituyendo pigpiod por
    una implementacion falsa. El robot vive en una sala virtual de 4x4 m con
    muebles; pigpio_sim.c traduce cada escritura de pin a movimiento y cada
    lectura de sensor a una medicion sobre ese mundo.
    Los fuentes de lib/ no se tocan: construir.sh compila con -I. para que el
    include de <pigpiod_if2.h> resuelva contra la cabecera del simulador, y el
    mismo codigo que corre en la Pi corre aqui.
    prueba_librobot ejercita cada modulo (issue #19) y compara contra la verdad
    del mundo: sensores, LEDs, movimientos basicos, control diferencial y
    odometria. Las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
    [mundo.c, pigpio_sim.c, pigpiod_if2.h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]
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2026-09-10 docs(evid): prueba de instalacion y compilacion cruzada del SDK
    El Toolchain-SDK se genera, se instala sin root en ~/robot-sdk y compila para
    ARM aarch64 (verificado con file: el binario no corre en x86). Cierra el
    issue #8.
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2026-09-10 docs(api): documenta la API publica de librobot (#13)
    Referencia completa de la biblioteca de control en docs/api-librobot.md:
    la fachada lib_robot, motores (control diferencial), sensores, LEDs,
    odometria y audio, con firmas, retornos, politica de errores (0/-1),
    versionado (SONAME librobot.so.1) y ejemplos. Enlazada desde el README y
    el indice de docs/.
    Cierra #13.
2026-09-10 docs(evid): ejecucion del binario ARM cross-compilado bajo qemu-user
    Compila la prueba de la biblioteca para aarch64 con el Toolchain-SDK y la
    corre bajo qemu-aarch64 (incluido en el SDK): pasa 18/18. Prueba que la
    cadena de compilacion cruzada produce binarios que ejecutan correctamente,
    sin la Raspberry. Script sim/construir_arm.sh y evidencia en
    docs/evidencias/ejecucion-cruzada-qemu.md.
    Avanza #10 y #19 (evidencia de ejecucion cruzada). Las capturas en la Pi
    fisica siguen pendientes del kit.
2026-09-10 test(sim): la prueba ejercita tambien la API de audio; guia de calibracion
    prueba_librobot ahora cubre el modulo de audio (init, volumen roundtrip,
    estado, listado), ademas de motores, sensores, LEDs y odometria: ejercita
    cada modulo de la API. Corre verde en el host y bajo qemu-aarch64 (21/21).
    Agrega docs/odometria.md con el procedimiento de calibracion en campo de
    velocidades de motor (#15), umbrales de sensores (#16) y constantes de
    odometria (#22) — y arregla la referencia colgante desde lib_odom.h.
    [prueba_librobot.c]
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2026-09-17 fix(net): el arranque del servidor baja de 2 min 10 s a 17 s
    robot-server declara Wants=network-online.target, asi que espera a
    systemd-networkd-wait-online. Esa unidad agotaba sus 120 s en cada
    arranque por dos motivos independientes, medidos en la Raspberry:
    1. eth0 sin cable. systemd instala de fabrica 80-wired.network, que la
    configura por DHCP; sin carrier se queda en estado "configuring" y
    wait-online espera a TODAS las interfaces gestionadas. Se agrega
    20-wired.network (gana por prioridad) con RequiredForOnline=no: la
    Ethernet sigue pidiendo IP y sirve de plan B para entrar al robot,
    pero ya no frena el arranque.
    2. dhcpcd y systemd-networkd sobre wlan0 a la vez. Se p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
2026-09-29 feat(audio): mezcla a mono para un solo parlante en el PAM8403
    La salida de audio deja el jack de 3.5 mm: el overlay audremap saca el
    PWM analogico por GPIO 18, que entra al amplificador PAM8403 a traves de
    un filtro RC, y de ahi a un solo parlante. El PAM8403 es estereo pero
    solo se cablea un canal.
    Con LIB_AUDIO_MONO cada bloque estereo se mezcla a (L+R)/2 antes de ir
    a ALSA, en la reproduccion y en los avisos: no se pierde lo que una
    pista trae solo por la derecha, y como los dos canales llevan lo mismo
    da igual cual de los dos GPIO quedo cableado. Se hace con memcpy porque
    el buffer es un arreglo de bytes sin alineacion garantizada para
    int16_t.
    Para ALSA nada cambia: sigue siendo la c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
2026-09-29 fix(yocto): librobot ya no aborta pseudo al cambiar sus fuentes
    Con S = ${WORKDIR}, do_unpack copiaba las fuentes nuevas encima de las
    viejas conservando el inodo, y ese inodo ya estaba enlazado (hardlink)
    por do_package en package/usr/src/debug. Como librobot esta en
    RM_WORK_EXCLUDE, el WORKDIR sobrevive entre builds y el primer build
    tras cambiar cualquier archivo de lib/ fallaba en do_install con
    "abort()ing pseudo client ... path mismatch". Hasta ahora se salvaba con
    bitbake -c clean librobot.
    Las fuentes pasan a ${WORKDIR}/lib (subdir=lib) y S apunta ahi: con S
    distinto de WORKDIR, base.bbclass vacia S antes de desempaquetar y cada
    archivo es un inodo nuevo. Los fuentes del simulador d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
2026-09-29 fix(lib): motores con nivel fijo mientras la PWM no pase por el PC817
    Con PWM de 1 kHz sobre IN1-IN4 los motores no se movieron. La causa mas
    probable: el PC817 con pull-up de 4.7 kOhm tarda decenas de microsegundos
    en apagarse y le recorta a cada ciclo parte del tiempo en alto, y con los
    ~2 V que cae el L298N, a velocidades medias (el 50 % por defecto del
    panel) el motor no llega a su tension de arranque.
    MOTOR_VELOCIDAD_VARIABLE (lib_motors.h) elige el modo y queda en 0: cada
    entrada es un nivel fijo, con la inversion del opto compensada, y
    cualquier velocidad distinta de cero va al maximo. motores_get() informa
    +-255, que es lo que el motor recibe, para que la odometria no subestime
    la v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
    [prueba_librobot.c]
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2026-10-04 docs: agrega el documento de aprendizaje continuo (AC1 a AC4)
    Necesidades de aprendizaje, tecnologias que contribuyeron, estrategias
    aplicadas y su evaluacion critica, apoyadas en commits, issues y los
    documentos de docs/.
    Es un borrador a revisar por los cuatro integrantes: el punto de partida
    del grupo y la evaluacion critica se armaron con lo que muestra el
    repositorio, y quedaron marcados como PENDIENTE.
    Refs #32
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2026-10-04 docs: agrega la lista de pendientes para la entrega
    Reune en un solo archivo lo que falta completar antes del 6 de octubre:
    las marcas PENDIENTE de los documentos, las tres afirmaciones que el
    repositorio todavia no respalda (PWM, cantidad de sensores y paquetes de
    desarrollo), las evidencias por capturar y los issues abiertos. Se borra
    antes de entregar.
    Refs #30, #31, #32, #33, #34
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2026-10-05 fix(server): abre el servidor HTTP antes de los sonidos de inicio
    lib_audio_notify() bloquea hasta que termina el MP3, y los dos sonidos de
    inicio retrasaban unos 6 s la apertura del puerto 8080: en la Raspberry Pi 4
    el servidor escuchaba a los 24.7 s del kernel. Ahora el daemon arranca justo
    despues de inicializar; los sonidos, los LEDs y los hilos de navegacion
    siguen en el mismo orden, asi que el robot no se mueve antes que antes. El
    modo autonomo se fija antes de abrir el puerto para que un cambio pedido
    desde el panel no quede pisado.
    [main.c]
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2026-10-06 docs(hw): agrega el modelo 3D de la carcasa y reescribe el chasis
    Carcasa circular de 215 mm impresa en 3D, en dos piezas con cierre a presion:
    modelo parametrico en CadQuery, STL, STEP y vistas. Los diagramas de hardware
    usan las vistas del modelo y la arquitectura de alimentacion real.
    Refs #3
    [boquilla_succion.step, boquilla_succion.stl, carcasa_inferior.step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]
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2026-10-06 feat: requerimientos opcionales y arreglo de detener la musica
    Desnivel: lib_caida lee dos sensores IR al piso (GPIO 4 y 8, pull-down);
    en autonomo el robot frena, retrocede y gira al lado contrario, en manual
    no deja avanzar. El simulador agrega una grada que el HC-SR04 no ve.
    Fin de ciclo: meta por minutos en autonomo o por m2 recorridos; al
    cumplirla el robot se detiene, suena notify_cycle_end.mp3 y el panel lo
    avisa. POST /api/ciclo.
    Playlist persistente: se edita desde el panel y se guarda en
    canciones/playlist.txt (temporal + rename); se reproduce en orden y en
    bucle. GET/POST /api/audio/playlist.
    Audio: pausar o reanudar ya no pisan un STOP pendiente; antes un aviso
    que coincidia c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
    [api.c, main.c, mundo.c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]
2026-10-06 fix(motores): lado de cada motor y freno solo al avanzar
    - En el robot armado el motor derecho va a la salida A del L298N
    (IN1/IN2, GPIO 5/6) y el izquierdo a la B (IN3/IN4, GPIO 23/24): con la
    asignacion anterior cada giro salia hacia el lado contrario. Se corrige
    en lib_motors.c y en el simulador.
    - Un obstaculo o un desnivel al frente solo frenan los motores si el robot
    va hacia adelante. Antes cortaban tambien el retroceso y los giros, y
    como el panel manda la orden una sola vez, el robot quedaba quieto.
    [main.c, pigpio_sim.c]
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2026-10-11 Cambios de Docu y final bug fixes(espero)
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2026-10-11 fix(server): espera a que el servidor responda en prueba_api.sh
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2026-10-12 fix(server): corrige la espera y la unidad de prueba_reinicio_systemd.sh
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2026-10-12 docs(server): corrige la causa del arranque lento en las pruebas
    Las pruebas 03 y 04 atribuian los 3,6 s de arranque al escaneo de la playlist.
    La causa real es el disco: la carpeta de trabajo estaba en /mnt/c (9p, WSL).
    El mismo binario abre el puerto a los 0,59 s sobre ext4, y el journal de la
    Raspberry Pi registra 0,44 s para el mismo escaneo de 9 pistas.
2026-10-12 docs: actualiza el README y los pendientes para cerrar el issue 33
    El README citaba 47 comprobaciones donde hoy son 49, mostraba la captura de
    la Raspberry Pi anterior a la del 6 de octubre y no listaba pruebas/ ni la
    licencia. TODO.md y PENDIENTES.md seguian marcando las metricas como
    pendientes aunque ya estan medidas y reportadas.
    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
2026-10-13 fix(navegacion): evadir a 6 cm con la velocidad real del robot
    El robot real va a unos 2 cm/s, pero el modelo de odometria suponia
    30 cm/s (el valor del simulador). Con esa velocidad el tiempo de choque
    bajaba de 1.2 s a unos 36 cm y el robot giraba lejos del obstaculo; ademas
    el umbral de distancia estaba en 20 cm.
    - ODOM_VEL_MAX_CM_S pasa a 2.0 y se puede redefinir al compilar.
    - DIST_OBSTACULO_CM pasa de 20 a 6 cm.
    - El simulador compila con -DODOM_VEL_MAX_CM_S=30.0 para que sus pruebas
    sigan comparando contra su robot de 28 cm/s.
    - Documentacion actualizada.
2026-10-13 fix(navegacion): tope de los giros segun la velocidad del modelo
    El tope suponia unos 180 grados/s y cortaba los giros del robot real,
    que con las llantas a 2 cm/s gira a unos 15 grados/s. Ahora se calcula
    con ODOM_VEL_MAX_CM_S y ODOM_ENTRE_EJES_CM, con el doble de margen.
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2026-10-15 fix(navegacion): obstaculo solo si cae en el pasillo de 20 cm del cuerpo
    Cada lectura del cono frontal se pasa al marco del robot: d*sin(desvio) a un
    costado de la linea de avance y d*cos(desvio) por delante del sensor. Es
    obstaculo solo si queda a menos de 10 cm de la linea (el robot mide ~20 cm)
    y a menos del umbral del panel por delante. Dos obstaculos con un hueco de
    20 cm o mas ya no lo detienen, ni uno lejano: antes, una lectura de 22 cm a
    60 grados lo frenaba aunque el umbral fuera de 5 cm.
    El cono pasa a 30-150 grados: un obstaculo que el robot va a rozar con el
    costado sale del haz de 60/120 al acercarse y aparece en 30/150.
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2026-10-16 docs: cambia la tira de cuadros por un GIF de la evasion
    El README muestra ahora un GIF del tramo de 0:04 a 0:21 del video, a
    triple velocidad y con la imagen estabilizada, en lugar de la tira de
    cuatro cuadros. Estabilizar deja quieto el piso, asi que el GIF solo
    guarda lo que se mueve entre cuadros: pesa 1.2 MB.
    Corrige la descripcion del video: el robot se detiene ante la tabla y
    gira sobre su eje. Al final del video la camara se mueve hacia un
    mueble, pero no se ve que el robot avance hasta ahi.
